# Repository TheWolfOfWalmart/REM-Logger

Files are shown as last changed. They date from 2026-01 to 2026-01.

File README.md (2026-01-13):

# REM Logger: Non-Contact Sleep Tracker

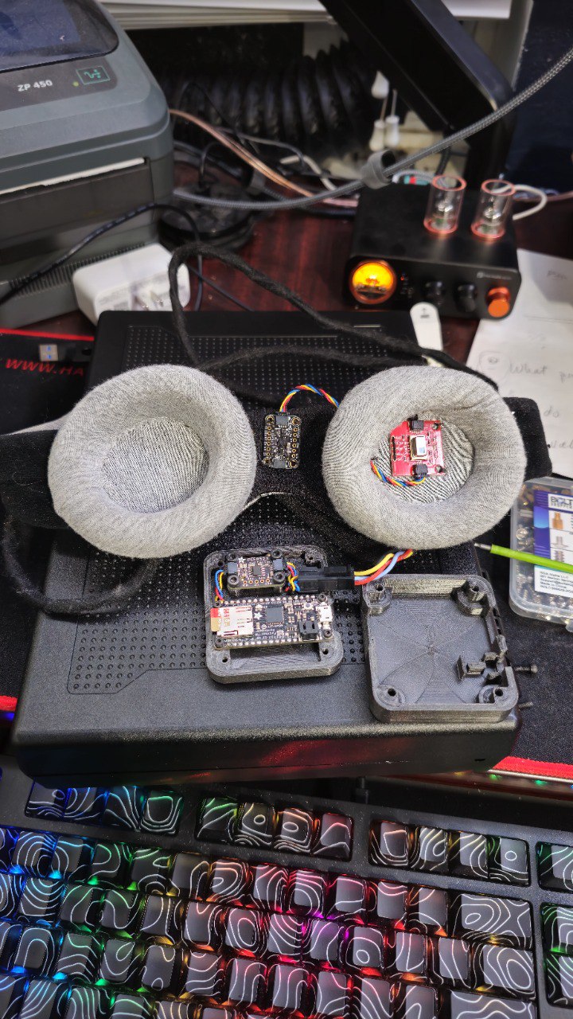
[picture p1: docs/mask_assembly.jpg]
Prototype Assembly

*Figure 1: The finished REM Logger wearable mask assembly.*

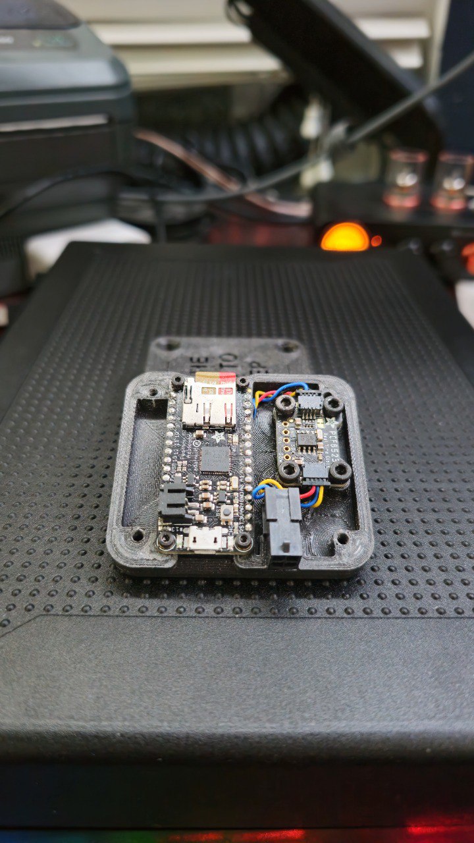
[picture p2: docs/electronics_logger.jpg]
Internal Electronics

*Figure 2: Internal view of the Adafruit Feather M0 logger and sensor wiring.*

## Overview
REM Logger is a wearable embedded system designed to detect REM (Rapid Eye Movement) sleep phases without invasive EEG electrodes. The project utilizes a novel sensor fusion approach, combining thermal imaging with accelerometry to infer sleep stages based on physiological markers.

## Problem Statement
Traditional sleep tracking (polysomnography) requires cumbersome wiring and electrodes, interfering with natural sleep. Consumer wearables often rely solely on heart rate and wrist movement, which can lack precision in distinguishing specific sleep stages like REM.

## Engineering Solution
This device is a custom-sewn eye mask integrating a microcontroller and sensor array designed to monitor two key REM indicators:
1.  **Rapid Eye Movement**: Detected via a **Grid-EYE Thermopile Array (8x8)**. The sensor measures the infrared radiation delta. As the eye moves, the apex (cornea) distance to the sensor changes, creating a detectable thermal signature.
2.  **Sleep Paralysis (Atonia)**: Detected via an **Accelerometer**. During REM, the body enters a state of temporary paralysis (atonia), meaning head movement should be near zero.

### Theory of Operation: IR Thermopile & Black Body Radiation
The eye-tracking mechanism relies on the principles of **Black Body Radiation**. Every object with a temperature above absolute zero emits infrared radiation. 
-   **Stefan-Boltzmann Law**: The sensor (AMG8833) detects the intensity of IR radiation, which is proportional to the fourth power of the object's absolute temperature ($P \propto T^4$).
-   **Distance Sensitivity**: While the cornea and the surrounding eyelid are at similar biological temperatures, the cornea's distinct shape (the "apex") and its movement create a dynamic change in the IR flux hitting the individual pixels of the 8x8 thermopile array.
-   **Non-Invasive & Passive Detection**: Unlike **Time-of-Flight (ToF)** sensors, which are *active* and must emit infrared light pulses to measure distance, the thermopile is a *passive* sensor. It detects naturally occurring radiation emitted by the body. This is a critical design choice for a sleep tracker, as it ensures zero light-bleed or electronic emission that could interfere with the user's circadian rhythm or sleep quality.
-   **EMF Safety**: By relying on passive thermal signatures, the device avoids placing active emitters (which can generate electromagnetic fields or heat) directly against the sensitive ocular region.

### Design for Comfort & Wearability
To ensure the device could be worn through the night:
-   **Anatomical Design**: A **Manta Sleep Mask** was selected as the base chassis specifically for its **offset eye cups**. This provided the necessary cavity around the eye socket to prevent pressure on the eyelids during REM while maintaining the sensors at an optimal, fixed distance from the cornea.
-   **Material Selection**: **Tesa tape** was utilized for all surfaces touching the face or body. This soft, fleece-like tape provided superior comfort and prevented skin irritation during long-duration sleep sessions.

## System Architecture
### Hardware
-   **Adafruit Feather M0 Adalogger**: Main microcontroller with integrated SD logging capabilities.
-   **AMG8833 Grid-EYE Sensor**: 8x8 IR thermopile array for eye-tracking.
-   **LIS3DH Accelerometer**: 3-axis motion tracking for atonia detection.
-   **PCF8523 RTC**: High-precision Real-Time Clock for timestamp synchronization.
-   **Custom 3D-Printed Case**: Lightweight enclosure for the Feather M0 and battery.

### Firmware & Features
-   **Signal Filtering**: Implements both Exponential Moving Average (EMA) and Simple Moving Average (SMA) to reduce sensor noise.
-   **Gravity Compensation**: Advanced normalization logic to isolate intentional head movements from static gravitational pull.
-   **Automatic Log Rotation**: Incremental file naming to prevent data loss across multiple sessions.
-   **Startup Delay**: 60-second warm-up window to allow sensors to calibrate before data acquisition begins.

## Analysis & Visualization
The project employed a multi-stage analysis pipeline to validate sensor data and detect sleep patterns:

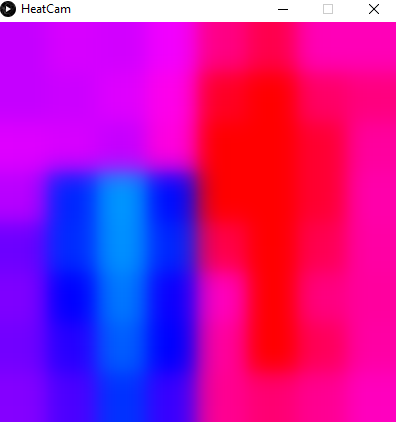
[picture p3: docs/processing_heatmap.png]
Processing Heatmap

*Figure 3: Real-time thermal visualization using Processing (Java). The 8x8 grid represents the IR intensity delta across the eye socket.*

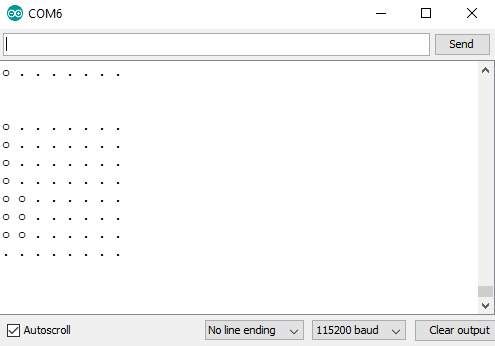
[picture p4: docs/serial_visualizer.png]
Serial Visualizer

*Figure 4: High-frequency data stream visualization during sensor calibration.*

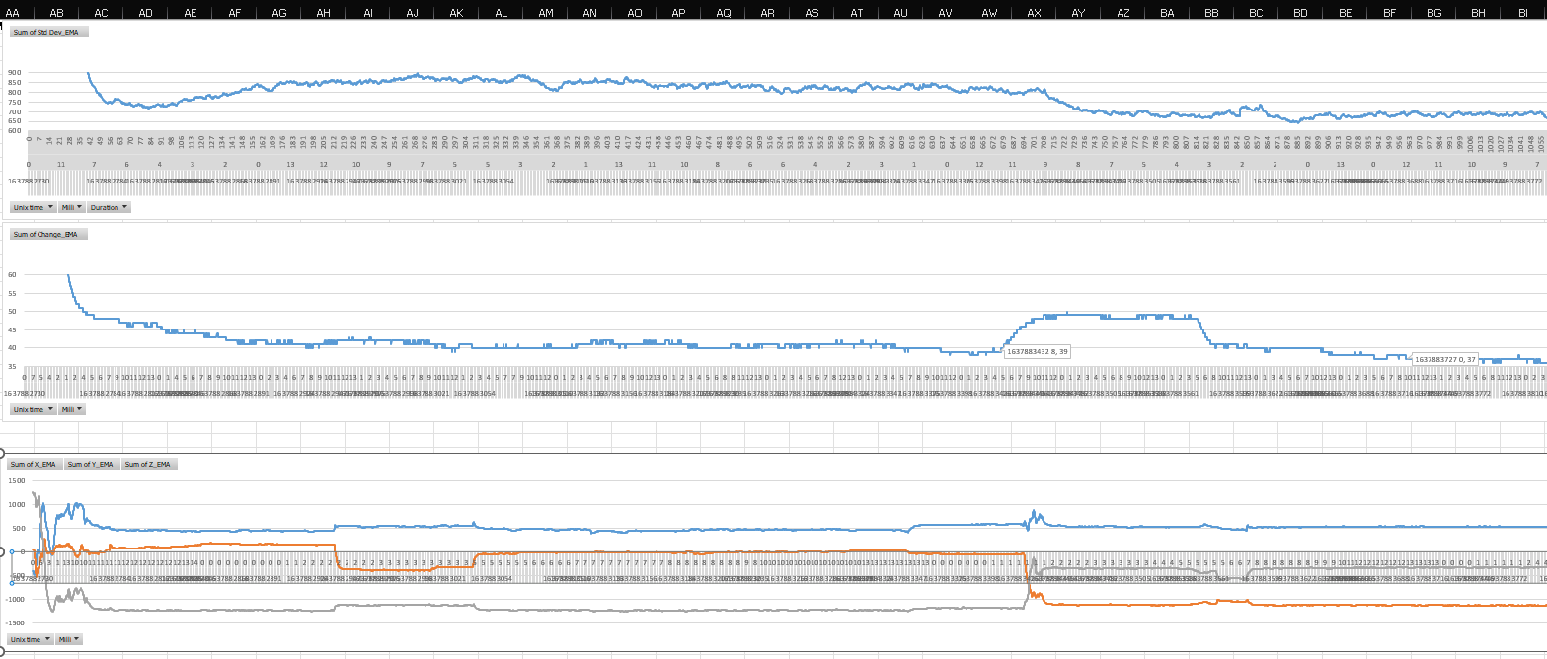
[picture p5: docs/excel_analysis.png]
Excel Pivot Tables

*Figure 5: Post-hoc data analysis using Excel Pivot Tables to correlate movement and thermal variance over an 8-hour session.*

## Data Validation & Results
Analysis of an 8-hour sleep session demonstrated the viability of this non-invasive approach. 
-   **Session Duration**: 7.89 Hours
-   **Data Points**: ~356,000 samples
-   **REM Detection**: Approximately **13.4%** of the session was identified as "REM-like" (High Eye Activity + Sleep Paralysis), correlating well with expected human sleep cycles (typically 20-25%).

*Note: The `Acc. Norm` (Normalized Acceleration) metric proved critical in filtering out "false positives" where head movement caused thermal variance.*

## Repository Structure
-   `/src/firmware`: Modernized Arduino C++ source code.
-   `/src/analysis`: Processing sketches for data visualization.
-   `/hardware`: 3D CAD files (SolidWorks/STL) for the enclosure.
-   `/data/samples`: Sample datasets from sleep tracking sessions.

--- 
*Project Status: Archived / Prototype*

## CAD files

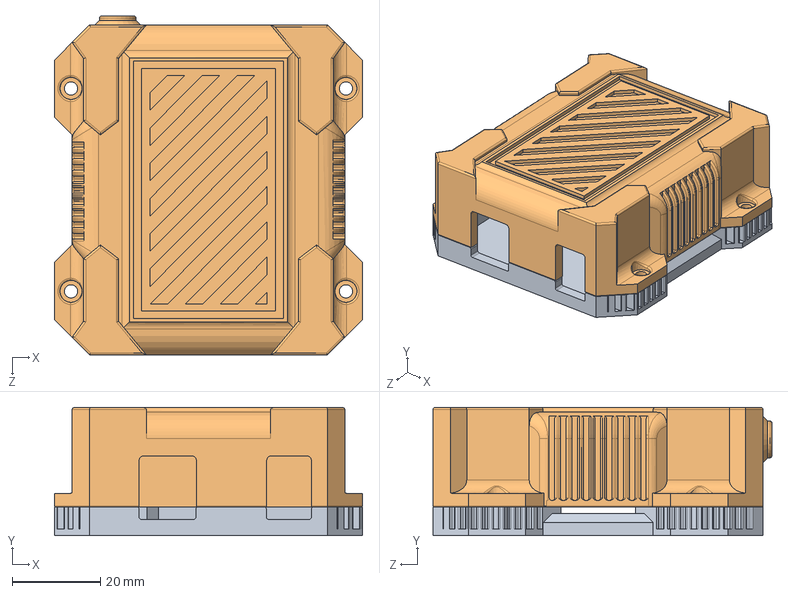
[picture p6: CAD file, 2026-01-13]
hardware/case/Uno Case.SLDASM
70.0 x 29.1 x 77.0 mm
reciever case bottom.stp
reciever case top.stp

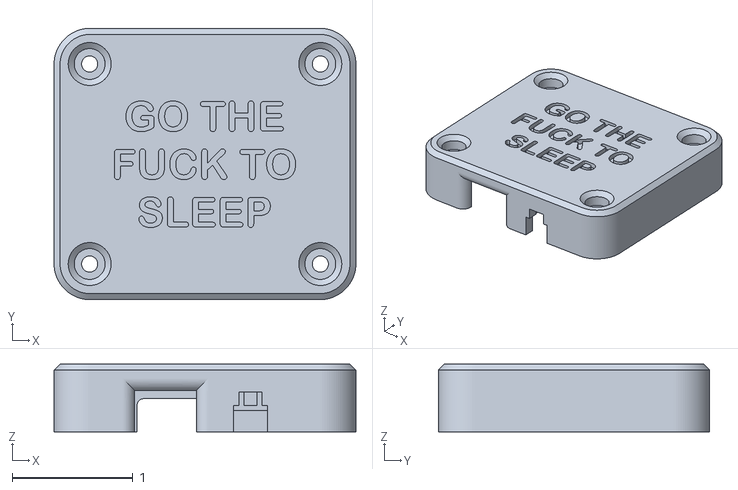
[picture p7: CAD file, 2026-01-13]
hardware/case/Case_Top.stl
2.50 x 2.25 x 0.562

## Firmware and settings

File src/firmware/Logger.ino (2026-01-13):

/**
 * @file Logger.ino
 * @brief Firmware for the Lucidity REM Sleep Tracker (v2.0 - Tuned).
 * 
 * This sketch handles high-frequency data acquisition from:
 * - AMG8833 Grid-EYE Thermal Camera (I2C)
 * - LIS3DH Accelerometer (I2C)
 * - PCF8523 Real Time Clock (I2C)
 * 
 * Features:
 * - Exponential Moving Average (EMA) & Simple Moving Average (SMA) filtering.
 * - Gravity Compensation & Normalized Accelerometer output.
 * - Start-up delay to avoid calibration noise.
 * 
 * @author TheWolfOfWalmart
 * @date 2021-11-23 (Updated)
 */

#include <Wire.h>
#include <SparkFun_GridEYE_Arduino_Library.h>
#include <Adafruit_LIS3DH.h>
#include <Adafruit_Sensor.h>
#include <RTClib.h>
#include <SparkFun_Qwiic_OpenLog_Arduino_Library.h> 
#include <Ewma.h>
#include <SPI.h>
#include <SD.h>
#include <MovingAverage.h>

// --- Configuration Constants ---
#define SD_CS_PIN 4      // Chip Select for SD card
#define LED_PIN   13     // Onboard LED for status/error blinking
#define ERROR_PIN 8      // Additional error indicator pin

/* --- Controls & Settings --- */
const bool  DEBUG_SERIAL   = true;   // Output to serial console
const bool  DEBUG_LOGGER   = false;  // Extra debug info in log file
const bool  WRITE_TO_LOG   = true;   // Enable SD card logging
const int   LOG_RATE_MS    = 0;      // Sampling interval (0 = max speed)

const float ACC_ALPHA      = 0.04;   // EMA Alpha for Accelerometer
const float TEMP_ALPHA     = 0.01;   // EMA Alpha for Temperature
const int   SMA_PERIOD     = 100;    // Window size for Simple Moving Average
const int   GRAV_COMP      = 1300;   // Gravity compensation value (for LIS3DH range)
const unsigned long START_DELAY_MS = 60000; // 60s warm-up delay

// --- Global Objects ---
Ewma accNormF(ACC_ALPHA);                     // EMA filter for normalized value from accelerometer
Ewma emaXF(ACC_ALPHA);                        // EMA filter for accelerometer X axis
Ewma emaYF(ACC_ALPHA);                        // EMA filter for accelerometer Y axis
Ewma emaZF(ACC_ALPHA);                        // EMA filter for accelerometer Z axis
Ewma emaStdDevF(TEMP_ALPHA);                  // EMA filter for temperature readings
Ewma emaChangeAvgF(TEMP_ALPHA);               // EMA filter for temperature readings
MovingAverage<long> smaStdDevF(SMA_PERIOD);    // SMA for temp readings
MovingAverage<long> smaChangeAvgF(SMA_PERIOD); // SMA filter for temperature readings

File sleepLog;                           
GridEYE grideye;                         
Adafruit_LIS3DH lis = Adafruit_LIS3DH(); 
RTC_PCF8523 rtc;                         

// --- State Variables ---
const char DAYS_OF_WEEK[7][12] = {"Sun", "Mon", "Tue", "Wed", "Thu", "Fri", "Sat"};
int pixelLast[64];
unsigned long unixLast;
int subSecCounter;
char currentLog[15] = "/ANALOG00.TXT"; 
unsigned long startTime = 0; // Timestamp of first sample


/**
 * @brief Blinks out an error code using the onboard LED.
 */
void error(uint8_t errno)
{
  while (true)
  {
    for (uint8_t i = 0; i < errno; i++)
    {
      digitalWrite(LED_PIN, HIGH);
      delay(100);
      digitalWrite(LED_PIN, LOW);
      delay(100);
    }
    for (uint8_t i = errno; i < 10; i++)
    {
      delay(200);
    }
  }
}

/**
 * @brief Writes the CSV header and configuration metadata to the log file.
 */
void writeLogHeader()
{
  DateTime now = rtc.now();
  sleepLog.print("Power-on time = ");
  sleepLog.print(DAYS_OF_WEEK[now.dayOfTheWeek()]);
  sleepLog.print(", ");
  sleepLog.print(now.month(), DEC);
  sleepLog.print("/");
  sleepLog.print(now.day(), DEC);
  sleepLog.print("/");
  sleepLog.print(now.year(), DEC);
  sleepLog.print(" ");
  sleepLog.print(now.hour(), DEC);
  sleepLog.print(":");
  sleepLog.print(now.minute(), DEC);
  sleepLog.print(":");
  sleepLog.println(now.second(), DEC);
  sleepLog.println();

  sleepLog.println("--Accelerometer--");
  sleepLog.print("Data Rate = 50Hz, Range = ");
  sleepLog.print(2 << lis.getRange());
  sleepLog.println("G\n");

  sleepLog.println("--Filter Settings--");
  sleepLog.print("Acc Alpha = "); sleepLog.println(ACC_ALPHA);
  sleepLog.print("Temp Alpha = "); sleepLog.println(TEMP_ALPHA);
  sleepLog.println();

  // CSV Columns
  sleepLog.println("Unix time,Milli,Duration,Avg. Temp,Std Dev,Std Dev_SMA,Std Dev_EMA,Change Avg.,Change_SMA,Change_EMA,X_Raw,Y_Raw,Z_Raw,X_EMA,Y_EMA,Z_EMA,Acc. Norm");
}

void setup(void)
{
  Wire.begin(); 
  Serial.begin(115200);
  grideye.begin();
  delay(50); 
  rtc.begin();

  if (!lis.begin(0x18))
  {
    Serial.println("Could not find LIS3DH accelerometer!");
    error(4);
  }
  
  lis.setRange(LIS3DH_RANGE_16_G);
  lis.setDataRate(LIS3DH_DATARATE_50_HZ);

  if (DEBUG_SERIAL)
  {
    Serial.println("LIS3DH Initialized.");
    Serial.print("Range = "); Serial.print(2 << lis.getRange()); Serial.println("G");
  }

  /* -- SD Card Initialization -- */
  if (!SD.begin(SD_CS_PIN))
  {
    Serial.println("Card init. failed!");
    error(2);
  }

  char filename[15];
  strcpy(filename, "/ANALOG00.TXT"); 

  for (uint8_t i = 0; i < 100; i++)
  {
    filename[7] = '0' + i / 10;
    filename[8] = '0' + i % 10;
    if (!SD.exists(filename))
    {
      strcpy(currentLog, filename);
      break;
    }
  }

  sleepLog = SD.open(currentLog, FILE_WRITE);
  if (!sleepLog)
  {
    Serial.println("Could not create log file.");
    error(3);
  }

  pinMode(LED_PIN, OUTPUT);
  pinMode(ERROR_PIN, OUTPUT);
  Serial.println("Ready!");

  if (WRITE_TO_LOG) 
  {
    writeLogHeader();
  }
  sleepLog.close();
}

uint8_t i = 0;

void loop()
{
  unsigned long startMillis = millis(); 

  float sum = 0.0;     
  float sumOfSq = 0.0; 
  float frameAvg;      
  float frameStdDev;
  float temps[64];
  float delta[64]; 
  float deltaSum = 0.0;     
  DateTime now = rtc.now(); 

  // --- Step 1: Data Acquisition (Grid-EYE) ---
  for (uint8_t i = 0; i < 64; i++) 
  {
    temps[i] = grideye.getPixelTemperature(i); 

    if (DEBUG_SERIAL)
    {
      Serial.print(temps[i]);
      Serial.print(" ");
      if ((i + 1) % 8 == 0) Serial.println();
    }
  }
  if (DEBUG_SERIAL) Serial.println();

  // --- Step 2: Statistical Processing ---
  for (uint8_t q = 0; q < 64; q++) 
  {
    delta[q] = abs(temps[q] - pixelLast[q]);
    sum += temps[q];
    sumOfSq += sq(temps[q]);
    pixelLast[q] = temps[q]; 
  }

  frameAvg = sum / 64.0;
  float sumSquaredDivN = sq(sum) / 64.0;
  frameStdDev = sumOfSq - sumSquaredDivN; 

  for (uint8_t i = 0; i < 64; i++)
  {
    deltaSum += delta[i];
  }
  float frameChangeAvg = deltaSum / 64.0;

  // Filters for Temp Stats
  int stdDevInt = (int)(frameStdDev * 100);       
  int changeAvgInt = (int)(frameChangeAvg * 100); 

  int emaStdDev = emaStdDevF.filter(stdDevInt);          
  int emaChangeAvg = emaChangeAvgF.filter(changeAvgInt); 

  smaStdDevF.push(stdDevInt);       
  smaChangeAvgF.push(changeAvgInt); 
  int smaStdDev = smaStdDevF.get(); 
  int smaChangeAvg = smaChangeAvgF.get();

  // --- Step 3: Accelerometer & Gravity Compensation ---
  lis.read();
  int rawX = lis.x;
  int rawY = lis.y;
  int rawZ = lis.z;

  int accNorm = 0;
  int axisData[3] = {rawX, rawY, rawZ};

  // Calculate Normalized Acceleration (Magnitude above gravity)
  for (int i = 0; i < 3; i++)
  {
    if (abs(axisData[i]) >= GRAV_COMP)
    {
      accNorm += abs(axisData[i]) - GRAV_COMP;
    }
  }
  
  // Filters for Accelerometer
  int emaNorm = accNormF.filter(accNorm); 
  int emaX = emaXF.filter(rawX);
  int emaY = emaYF.filter(rawY);
  int emaZ = emaZF.filter(rawZ);

  // --- Step 4: Time Tracking ---
  unsigned long unixNow = now.unixtime();
  if (unixNow != unixLast) subSecCounter = 0;
  else subSecCounter++;
  unixLast = unixNow;

  if (startTime == 0)
  {
    startTime = unixNow;
  }
  unsigned long duration = unixNow - startTime;

  // --- Step 5: Logging ---
  if (WRITE_TO_LOG) 
  {
    // Skip logging if within start-up delay window
    if (millis() < START_DELAY_MS)
    {
      if (DEBUG_SERIAL) Serial.println("Waiting for warm-up...");
      delay(LOG_RATE_MS);
      return; 
    }
    
    sleepLog = SD.open(currentLog, FILE_WRITE);
    if (sleepLog)
    {
      sleepLog.print(unixNow);          sleepLog.print(",");
      sleepLog.print(subSecCounter);    sleepLog.print(",");
      sleepLog.print(duration);         sleepLog.print(",");
      sleepLog.print(frameAvg);         sleepLog.print(",");
      sleepLog.print(frameStdDev);      sleepLog.print(",");
      sleepLog.print(smaStdDev);        sleepLog.print(",");
      sleepLog.print(emaStdDev);        sleepLog.print(",");
      sleepLog.print(frameChangeAvg);   sleepLog.print(",");
      sleepLog.print(smaChangeAvg);     sleepLog.print(",");
      sleepLog.print(emaChangeAvg);     sleepLog.print(",");
      sleepLog.print(rawX);             sleepLog.print(",");
      sleepLog.print(rawY);             sleepLog.print(",");
      sleepLog.print(rawZ);             sleepLog.print(",");
      sleepLog.print(emaX);             sleepLog.print(",");
      sleepLog.print(emaY);             sleepLog.print(",");
      sleepLog.print(emaZ);             sleepLog.print(",");
      sleepLog.print(emaNorm);          sleepLog.println();
      
      sleepLog.close();
    }
  }

  if (DEBUG_SERIAL)
  {
    Serial.print("Loop Time: ");
    Serial.print(millis() - startMillis);
    Serial.println("ms");
  }

  delay(LOG_RATE_MS);
}

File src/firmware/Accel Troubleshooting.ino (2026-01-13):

// Basic demo for accelerometer readings from Adafruit LIS3DH

#include <Wire.h>
#include <Adafruit_LIS3DH.h>
#include <Adafruit_Sensor.h>
#include <SparkFun_Qwiic_OpenLog_Arduino_Library.h>
OpenLog myLog; // Create instance

// software SPI
// Adafruit_LIS3DH lis = Adafruit_LIS3DH(LIS3DH_CS, LIS3DH_MOSI, LIS3DH_MISO, LIS3DH_CLK);
// hardware SPI
// Adafruit_LIS3DH lis = Adafruit_LIS3DH(LIS3DH_CS);
// I2C
Adafruit_LIS3DH lis = Adafruit_LIS3DH();
unsigned long counter = 0;

void setup(void)
{
    Wire.begin();
    myLog.begin(0x1E); // Open connection to OpenLog (no pun intended)
    Serial.begin(115200);
    while (!Serial)
        delay(10); // will pause Zero, Leonardo, etc until serial console opens

    Serial.println("LIS3DH test!");

    if (!lis.begin(0x18))
    { // change this to 0x19 for alternative i2c address
        Serial.println("Couldnt start");
        while (1)
            yield();
    }
    Serial.println("LIS3DH found!");

    lis.setRange(LIS3DH_RANGE_4_G); // 2, 4, 8 or 16 G!

    Serial.print("Range = ");
    Serial.print(2 << lis.getRange());
    Serial.println("G");

    lis.setDataRate(LIS3DH_DATARATE_400_HZ);
    Serial.print("Data rate set to: ");
    switch (lis.getDataRate())
    {
    case LIS3DH_DATARATE_1_HZ:
        Serial.println("1 Hz");
        break;
    case LIS3DH_DATARATE_10_HZ:
        Serial.println("10 Hz");
        break;
    case LIS3DH_DATARATE_25_HZ:
        Serial.println("25 Hz");
        break;
    case LIS3DH_DATARATE_50_HZ:
        Serial.println("50 Hz");
        break;
    case LIS3DH_DATARATE_100_HZ:
        Serial.println("100 Hz");
        break;
    case LIS3DH_DATARATE_200_HZ:
        Serial.println("200 Hz");
        break;
    case LIS3DH_DATARATE_400_HZ:
        Serial.println("400 Hz");
        break;

    case LIS3DH_DATARATE_POWERDOWN:
        Serial.println("Powered Down");
        break;
    case LIS3DH_DATARATE_LOWPOWER_5KHZ:
        Serial.println("5 Khz Low Power");
        break;
    case LIS3DH_DATARATE_LOWPOWER_1K6HZ:
        Serial.println("16 Khz Low Power");
        break;
    }
    myLog.print("X");
    myLog.print(",");
    myLog.print("Y");
    myLog.print(",");
    myLog.print("Z");
    myLog.println();
}

void loop()
{
    unsigned long milliStart = millis();
    lis.read(); // get X Y and Z data at once

    /*
    // Then print out the raw data
    Serial.print("X:  "); Serial.print(lis.x);
    Serial.print("  \tY:  "); Serial.print(lis.y);
    Serial.print("  \tZ:  "); Serial.print(lis.z);

    /* Or....get a new sensor event, normalized */
    // sensors_event_t event;
    // lis.getEvent(&event);

    /* Display the results (acceleration is measured in m/s^2)
    Serial.print("\t\tX: "); Serial.print(event.acceleration.x);
    Serial.print(" \tY: "); Serial.print(event.acceleration.y);
    Serial.print(" \tZ: "); Serial.print(event.acceleration.z);
    Serial.println(" m/s^2 ");
  */
    unsigned long millisEnd = millis();
    unsigned long elapsed = milliStart - millisEnd;
    myLog.print(elapsed);
    myLog.print(",");
    myLog.print(lis.x);
    myLog.print(",");
    myLog.print(lis.y);
    myLog.print(",");
    myLog.print(lis.z);
    myLog.println();
    myLog.syncFile();

    // delay(200);
}

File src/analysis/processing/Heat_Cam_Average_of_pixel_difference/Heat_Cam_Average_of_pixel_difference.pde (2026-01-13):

import processing.serial.*; //<>// //<>// //<>// //<>// //<>// //<>// //<>// //<>// //<>// //<>//

String myString = null;
Serial myPort;  // The serial port
int comPort = 0;
float [] temps = new float [64];
Table thermTable;    // Table for outputting GridEye sensor readings
Table accTable;    // Table for outputting accelerometer data 
int sampleRate = 100;    // Sample rate in milliseconds
//done
float frameMin;    //lowest temp in frame
float frameMax;    //highest temp in frame
float frameAvg;    //avg temp of frame
float frameStdDev;    //Std. Dev. of frame Σ(xi2)-(Σ xi)2/n Sum of square shortcut
float frameChangeAvg;    // Avg of inter-pixel delta between frames, measure of how much change is happening in frame
float []delta = new float[64];    // Array to keep the differenes between current pixel and previous pixel
float []pixelLast = new float [64];    // Previous pixel value

// int hottestPixel;    //XY of hottest pixel in frame

void setup() {

  size(400, 400);  // Size must be the first statement
  noStroke();
  frameRate(30);

  printArray(Serial.list());     // Print a list of connected serial devices in the console
  myPort = new Serial(this, Serial.list()[comPort], 115200);    //Active comport changed here
  myPort.clear();    // Throw out the first chunk in case we caught it in the middle of a frame
  myString = myPort.readStringUntil(13);    //Read until carriage return
  myString = null;
  colorMode(HSB, 360, 100, 100);    // change to HSB color mode, this will make it easier to color code the temperature data

  /* Setup table for thermopile data */
  thermTable = new Table();
  thermTable.addColumn("Timestamp");
  thermTable.addColumn("Hour");
  thermTable.addColumn("Minute");
  thermTable.addColumn("Second");
  thermTable.addColumn("Millisecond");
  thermTable.addColumn("Avg. Temp");
  thermTable.addColumn("Frame Change Average"); 
  thermTable.addColumn("Std. Dev.");
  thermTable.addColumn("Min. Temp");
  thermTable.addColumn("Max Temp");

  /* Setup table for accelerometer data */
  /*accTable = new Table();
   accTable.addColumn("Timestamp");
   accTable.addColumn("X Axis");
   accTable.addColumn("Y Axis");
   accTable.addColumn("Z Axis");*/
}

void draw() { 

  float sum = 0.0;    //(Σ xi)^2 Sum of all temps in frame for Std. Dev. calculation
  float sumQ = 0.0;    // Σ(xi2)  Sum of square of all temps in frame for Std. Dev. calculation


  // When there is a sizeable amount of data on the serial port
  // read everything up to the first linefeed
  if (myPort.available() > 64) {
    myString = myPort.readStringUntil(13);

    // generate an array of strings that contains each of the comma
    // separated values

    if (myString != null) {
      myString = trim(myString);
      String splitString[] = splitTokens(myString, ",");
      //printArray(splitString);

      /* Once String is full of temp data, start splitting processing */
      if (splitString.length == 64) {    
        float deltaSum = 0;    //variable for average-of-pixel-change function

        for (int q = 0; q < 64; q++) {     //<>//
          /* subtract current pixel or last pixel, whichever is smallest, from whichever is largest, and store in array*/
          println("max =" + max(float(splitString[q]), pixelLast[q]));
          println("min =" + min(float(splitString[q]), pixelLast[q]));
          delta[q] = max(float(splitString[q]), pixelLast[q])- min(float(splitString[q]), pixelLast[q]);
          println("Pixel delta =" + delta[q]);

          frameAvg += float(splitString[q]);
          sum += float(splitString[q]);    // (Σ xi)^2 Sum of all temps in frame
          sumQ += sq(float(splitString[q]));    // Σ(xi^2)  Sum of square of all temps in frame

          println("Temp", q, "=", splitString[q]);

          if (q == 63) {

            println("sum = ", sum);
            sum = sq(sum);    // Square the sum of all temps
            println("sum^2 = ", sum);
            println("sumQ = ", sumQ);
            sum /= 64;
            println("sum / q =", sum);
            frameStdDev = sumQ - sum;    // Finish running Std. Dev.
            //println("Σ(xi2) - (Σ xi)2", frameStdDev);            
            println("Std. Dev. = ", frameStdDev);
          }
          temps[q] = map(float(splitString[q]), 33, 39, 100, 360);    //temps get mapped into color scaled values at this point
          pixelLast[q] = float(splitString[q]);    // store each pixel value  to be used in delta calculation
        }    // Things to do every frame 
        for (int i = 0; i < 64; i++) {
          deltaSum += delta[i];
        }
        frameChangeAvg = deltaSum/64;
        println(frameChangeAvg);
        frameMin = min(float(splitString));    // Find min temp in frame array
        frameMax = max(float(splitString));    // Find max temp in frame array
        //frameAvg /= float(splitString.length);    //Average temp of frame is recorded
      }
    }
  }


  /*Prepare variables needed to draw our heatmap*/
  int x = 0;
  int y = 0;
  int i = 0;
  background(0);   // Clear the screen with a black background


  /* each GridEYE pixel will be represented by a 50px square: 
   because 50 x 8 = 400, we draw squares until our y location
   is 400 */

  while (y < 400) {


    // for each increment in the y direction, draw 8 boxes in the 
    // x direction, creating a 64 pixel matrix
    while (x < 400) {
      // before drawing each pixel, set our paintcan color to the 
      // appropriate mapped color value
      fill(temps[i], 100, 100);
      rect(x, y, 50, 50);
      x = x + 50;
      i++;
    }

    y = y + 50;
    x = 0;
  }

  filter(BLUR, 10);    // Add a gaussian blur to the canvas in order to create a rough visual interpolation between pixels.

  /* time stamp variables that will get replaced by RTC */
  int ms = millis();
  int s = second();
  int m = minute();
  int h = hour();
  String time = h + ":" + m + ":" + s + ":" + ms;



  /* Write statistics for thermal to table and save */
  TableRow thermRow = thermTable.addRow();
  thermRow.setString("Timestamp", time);    //Finish when you get RTC all figured out
  thermRow.setFloat("Hour", h);
  thermRow.setFloat("Minute", m);
  thermRow.setFloat("Second", s);
  thermRow.setFloat("Millisecond", ms);
  thermRow.setFloat("Avg. Temp", frameAvg);    // Record average of frame in table 
  thermRow.setFloat("Frame Change Average", frameChangeAvg);    // Record the average of inter-pixel delta between frames
  thermRow.setFloat("Std. Dev.", frameStdDev);    // Record standard deviation of frame in table
  thermRow.setFloat("Min. Temp", frameMin);    // Record min temp in frame
  thermRow.setFloat("Max Temp", frameMax);    // Record max temp in frame
  saveTable(thermTable, "Thermal.csv");   //Commented for debugging. Consider putting in global boolean controlled if

  /* Write values for accelerometer to table and save */
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
